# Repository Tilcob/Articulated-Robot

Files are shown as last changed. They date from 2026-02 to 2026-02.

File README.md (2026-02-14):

# 3DOF Robotic Arm Controller (Arduino Nano)

## Overview

This project implements a 3DOF robotic arm controller using an Arduino Nano.
The system includes:

* Analytical forward and inverse kinematics
* Potentiometer-based Cartesian target input (X, Y, Z)
* Button-based target commit (short press)
* Long-press trajectory execution (predefined waypoints)
* Smooth joint motion control
* Configurable servo calibration and joint limits

The kinematic model is consistent with the following convention:

```
x =  cos(q1) * (L1 cos(q2) + L2 cos(q2+q3))
y = -sin(q1) * (L1 cos(q2) + L2 cos(q2+q3))
z =  h + L1 sin(q2) + L2 sin(q2+q3)
```

The negative sign in the Y coordinate is fixed and part of the model.

---

## Hardware Requirements

* Arduino Nano (ATmega328)
* 3 RC servos (Base, Shoulder, Elbow)
* Optional gripper servo
* 3 potentiometers (X, Y, Z)
* Optional gripper potentiometer
* 1 momentary push button
* External 5–6V servo power supply (recommended)

---

## Wiring

### Potentiometers

Each potentiometer:

* One side → 5V
* Other side → GND
* Middle pin → Analog input (A0–A3)

### Button

Configured with `INPUT_PULLUP`.

Wiring:

```
Pin 2  ---- Button ---- GND
```

* Not pressed → HIGH
* Pressed → LOW

### Servos

* Signal pins defined in `Config.h`
* Power servos from external supply
* Connect grounds together (Arduino GND ↔ Servo GND)

---

## Project Structure

* `Config.h` — geometry, limits, pins, calibration
* `Types.h` — basic data structures
* `Kinematics.*` — forward and inverse kinematics
* `Input.*` — potentiometer + button handling
* `Mapping.*` — joint angles → servo degrees
* `Motion.*` — smooth motion controller
* `Trajectory.*` — waypoint-based path execution
* `main.cpp` — system integration

---

## Operation Modes

### 1. Manual Target Mode (Short Button Press)

1. Adjust X, Y, Z using potentiometers.
2. Press the button briefly.
3. The target is latched and the arm moves to that position.

### 2. Trajectory Mode (Long Press > 700 ms)

1. Hold the button.
2. After release, trajectory execution begins.
3. The arm moves through predefined waypoints in `Trajectory.cpp`.

---

## Defining Custom Trajectories

Edit `Trajectory.cpp`:

```cpp
const Waypoint TRAJ_POINTS[] = {
    { {0.11f,  0.00f, 0.09f}, 0.5f },
    { {0.10f,  0.03f, 0.11f}, 0.5f },
    { {0.08f, -0.03f, 0.06f}, 0.2f }
};
```

Each waypoint contains:

* Cartesian position (meters)
* Gripper value (0.0–1.0)

---

## Motion Control

The motion controller:

* Limits joint speed (`MAX_SPEED_DEG_PER_S`)
* Moves joints smoothly toward targets
* Detects arrival within tolerance
* Advances trajectory automatically

---

## Calibration

Adjust in `Config.h`:

* `BASE_ZERO_DEG`
* `SHOULDER_ZERO_DEG`
* `ELBOW_ZERO_DEG`
* `*_SIGN`

Procedure:

1. Move arm mechanically to mathematical zero pose.
2. Set servo zero angles accordingly.
3. Adjust sign if joint moves in wrong direction.

---

## Inverse Kinematics

The IK uses a stable atan2-based solution:

```
q1 = atan2(-y, x)
q3 = atan2(±sqrt(1 - c3²), c3)
q2 = alpha - beta
```

Advantages:

* Stable near singularities
* Supports elbow-up and elbow-down configurations
* No acos flipping issues

---

## Safety Notes

* Always power servos from external supply.
* Avoid commanding unreachable targets.
* Ensure mechanical limits match software limits.

---

Serial Monitor: Permitted coordinates (depending on `h`, `L1`, `L2`)

Entries in the Serial Monitor are **absolute target points in the base coordinate system** in **metres**:

```
x y z [g]
```

* `x, y, z` in metres
* optional `g` as gripper value from `0.0 .. 1.0`

Relative TCP commands are also possible:

```
t dx dy dz [g]
```

Here, `(dx,dy,dz)` is specified in the current TCP coordinate system and is converted internally to the base system.

### Geometric conditions for valid targets

With

* `r = sqrt(x² + y²)`
* `d = sqrt(r² + (z - h)²)`

the following must apply:

* `R_MIN <= r <= R_MAX`
* `Z_MIN <= z <= Z_MAX`
* `|L1 - L2| <= d <= (L1 + L2)`

This is the combination of the configured cylindrical boundaries and the actual 2-link reachability.

### Current figures from `Config.h`

* `L1 = 0.080 m`
* `L2 = 0.068 m`
* `h  = 0.027 m`
* `R_MIN = 0.050 m`
* `R_MAX = L1 + L2 = 0.148 m`
* `Z_MIN = h - 0.02 = 0.007 m`
* `Z_MAX = h + 0.80*(L1+L2) = 0.1454 m`
* Additional IK ring: `0.012 m <= d <= 0.148 m`

### Examples of permitted entries

* `0.10 0.00 0.08`
* `0.09 0.03 0.11 0.6`
* `t 0.01 0.00 -0.01`

If a target is outside the workspace, the firmware reports `WS ERR` or `IK ERR`.

---

## Future Improvements

Possible extensions:

* Cartesian linear interpolation between waypoints
* Trapezoidal acceleration profiles
* Closed-loop control with encoders
* Serial command interface (G-code style)

---

## License

Personal educational project.

---

Developed for Arduino Nano 3DOF robotic arm experimentation.

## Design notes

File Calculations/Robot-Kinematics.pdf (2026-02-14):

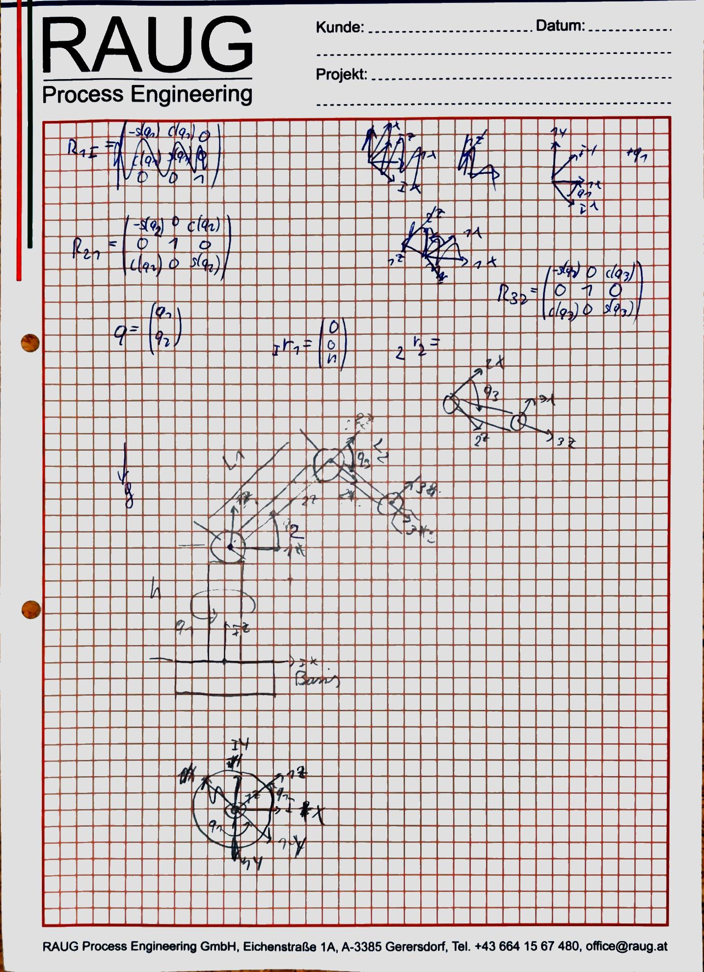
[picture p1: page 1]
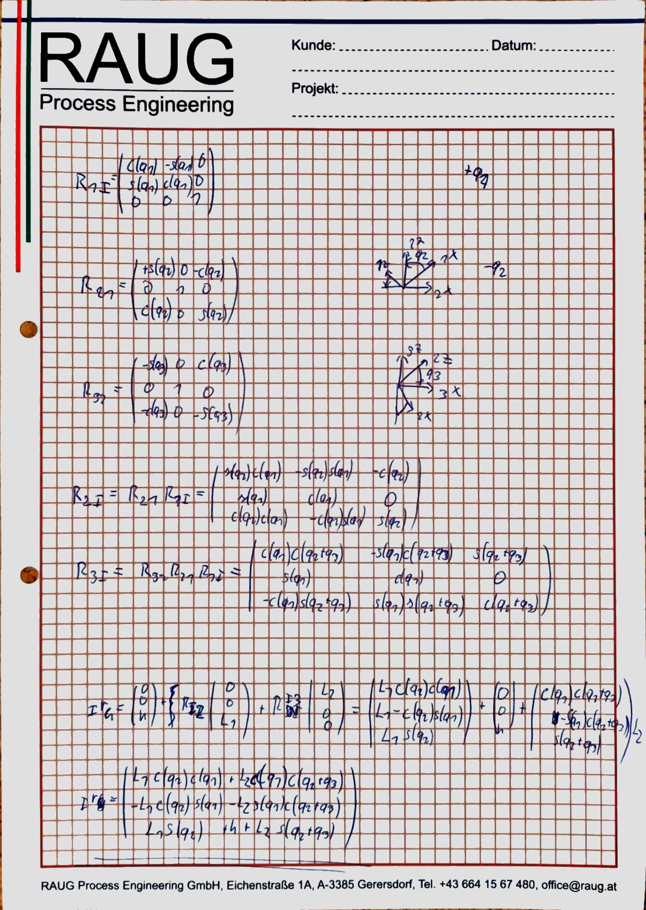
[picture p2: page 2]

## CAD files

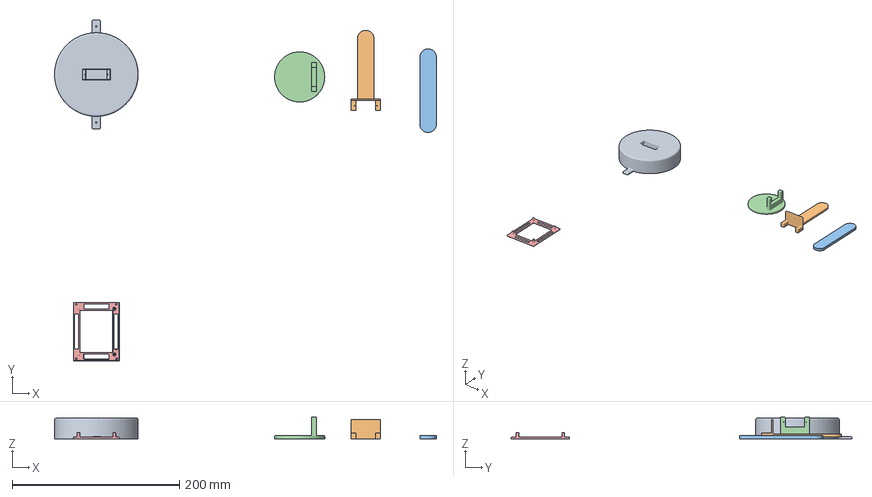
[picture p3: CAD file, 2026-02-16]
CAD/Articulated-Robot.3mf
456.5 x 407.2 x 26.0 mm
Base.stl
L1.stl
L2.stl
Shoulder.stl
PCB-Base.stl

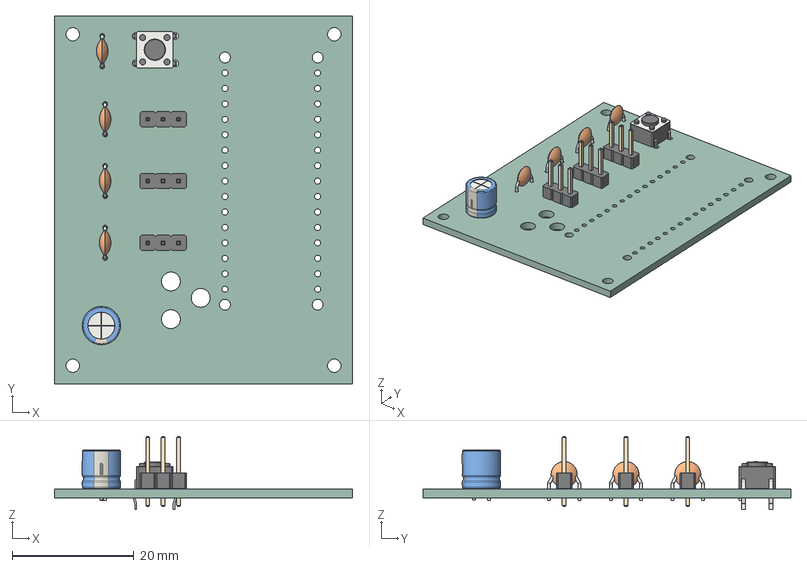
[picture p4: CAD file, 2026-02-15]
Circuit-Diagram/Articulated-Robot/Articulated-Robot.step
49.0 x 60.5 x 12.0 mm
PinHeader_1x03_P2.54mm_Vertical x 3
C_Disc_D4.3mm_W1.9mm_P5.00mm x 4
CP_Radial_D6.3mm_P2.50mm
SW_PUSH_6mm_H4.3mm
Articulated-Robot_PCB

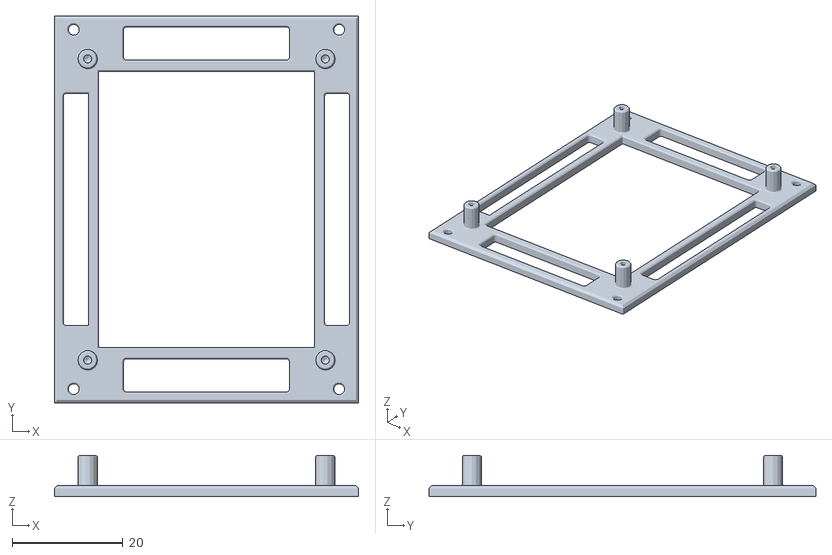
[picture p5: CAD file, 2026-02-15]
CAD/PCB-Base.stl
55.0 x 70.0 x 7.50

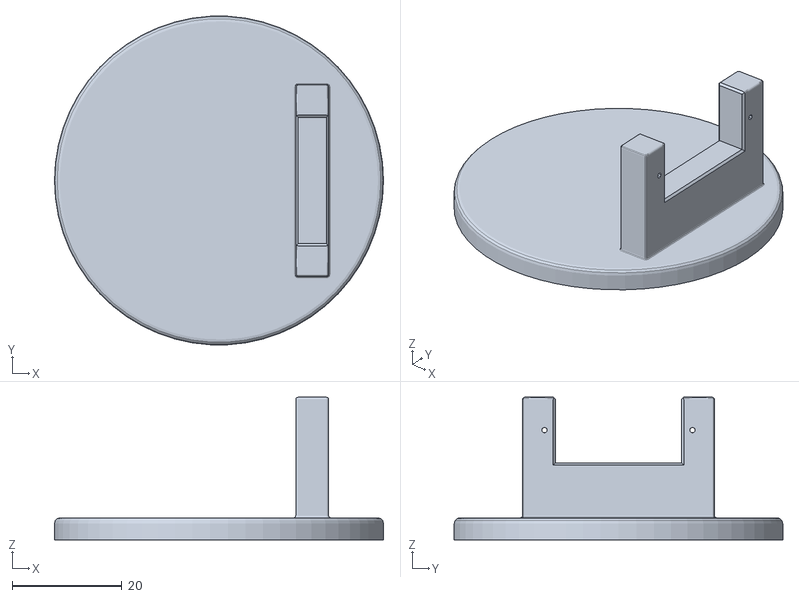
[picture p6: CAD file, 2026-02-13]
CAD/Shoulder.stl
60.0 x 59.9 x 26.0

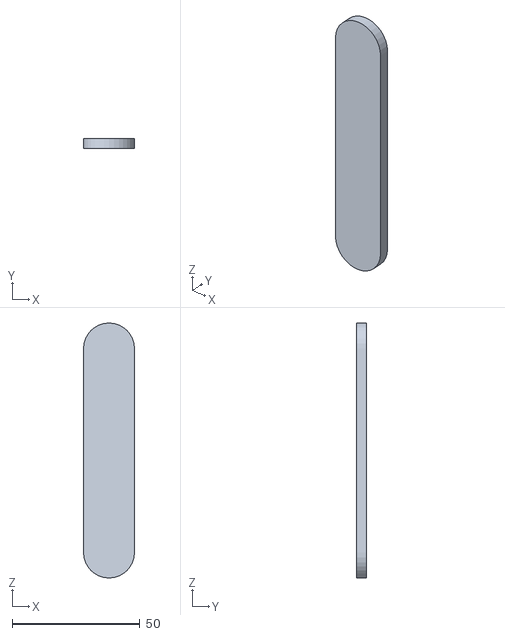
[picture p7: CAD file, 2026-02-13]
CAD/L2.stl
20.0 x 4.00 x 100.0

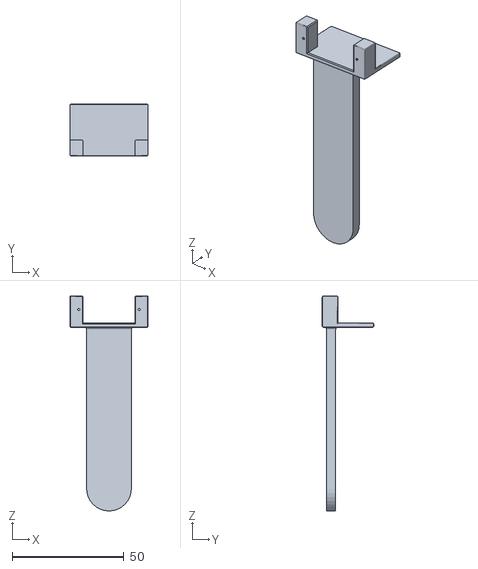
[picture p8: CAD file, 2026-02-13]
CAD/L1.stl
35.0 x 23.0 x 96.0

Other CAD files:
CAD/Articuled-Robot.iam
CAD/Base.iam
CAD/Base.ipt
CAD/L1.ipt
CAD/L2.ipt
CAD/Motor.ipt
CAD/OldVersions/Articuled-Robot.0015.iam
CAD/OldVersions/Base.0003.ipt
CAD/OldVersions/Base.0005.iam
CAD/OldVersions/Base.0012.ipt
CAD/OldVersions/L1.0004.ipt
CAD/OldVersions/L2.0003.ipt
CAD/OldVersions/Motor.0005.ipt
CAD/OldVersions/PCB-Base.0009.ipt
CAD/OldVersions/Shoulder.0004.ipt
CAD/PCB-Base.ipt
CAD/PCB.ipt
CAD/Shoulder.ipt

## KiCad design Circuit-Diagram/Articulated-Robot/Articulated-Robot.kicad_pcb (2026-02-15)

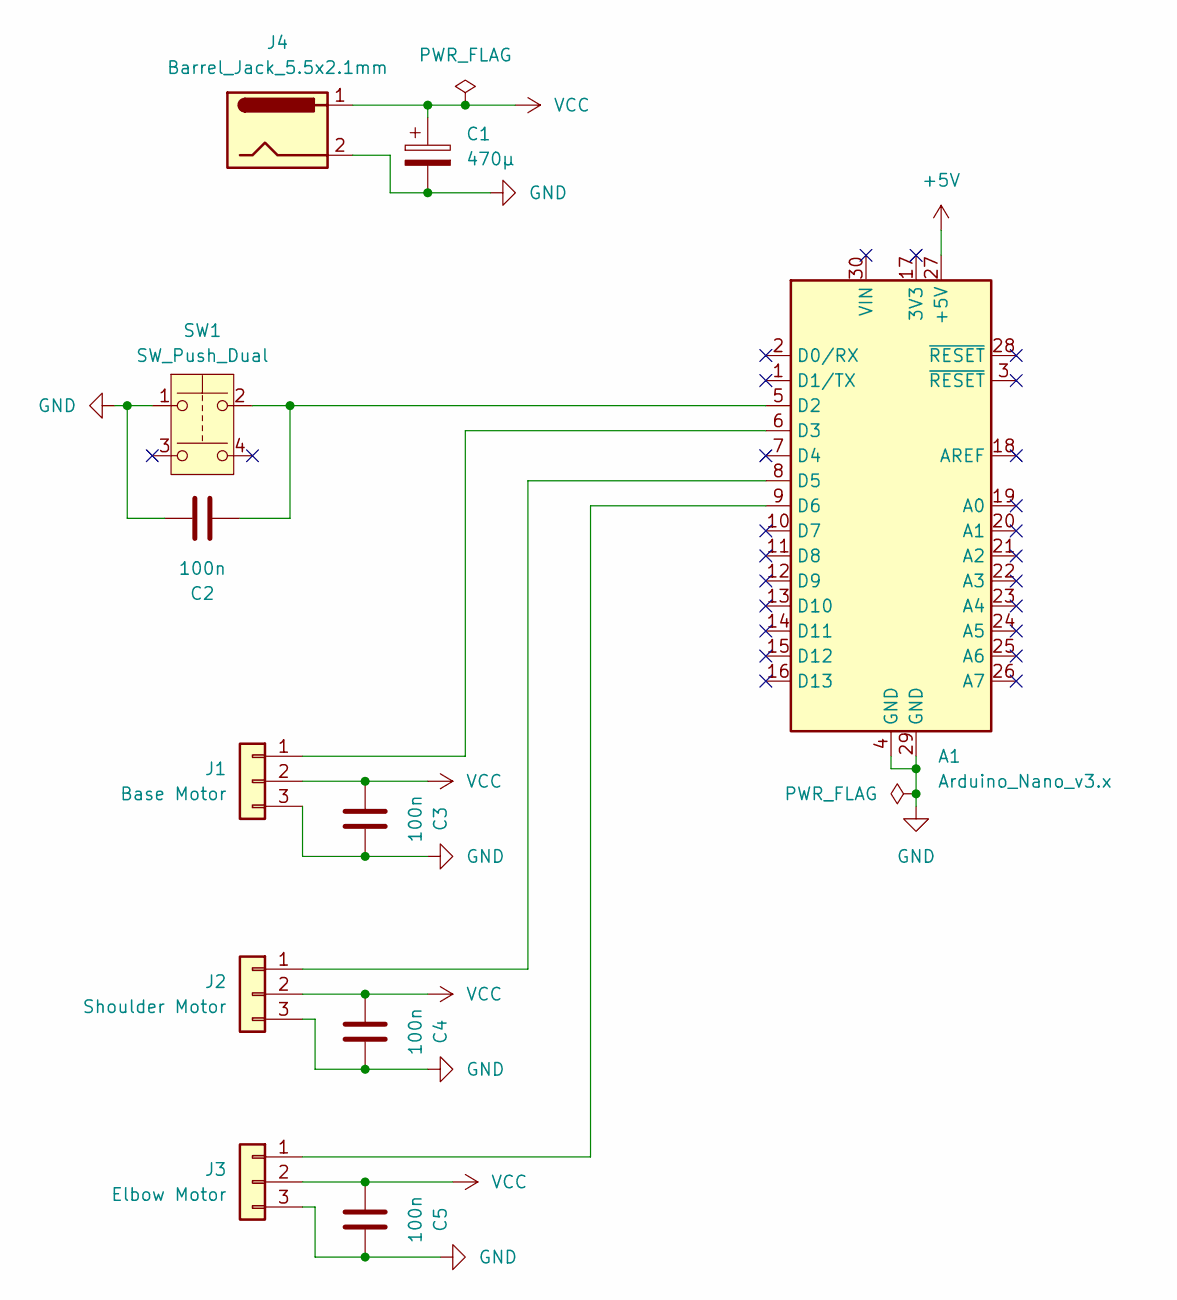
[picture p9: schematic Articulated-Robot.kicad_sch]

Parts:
A1: Arduino_Nano_v3.x; Arduino_Nano_WithMountingHoles
C1: 470µ; CP_Radial_D6.3mm_P2.50mm
C2, C3, C4, C5: 100n; C_Disc_D4.3mm_W1.9mm_P5.00mm
J1: Base Motor; PinHeader_1x03_P2.54mm_Vertical
J2: Shoulder Motor; PinHeader_1x03_P2.54mm_Vertical
J3: Elbow Motor; PinHeader_1x03_P2.54mm_Vertical
J4: Barrel_Jack_5.5x2.1mm
SW1: SW_Push_Dual; SW_PUSH_6mm_H4.3mm

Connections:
+5V: A1.27 (+5V)
GND: A1.4 (GND), A1.29 (GND), C1.2, C2.1, C3.1, C4.1, C5.1, J1.3, J2.3, J3.3, J4.2, SW1.1
unnamed: A1.5 (D2), C2.2, SW1.2
unnamed: A1.6 (D3), J1.1
unnamed: A1.8 (D5), J2.1
unnamed: A1.9 (D6), J3.1
VCC: C1.1, C3.2, C4.2, C5.2, J1.2, J2.2, J3.2, J4.1

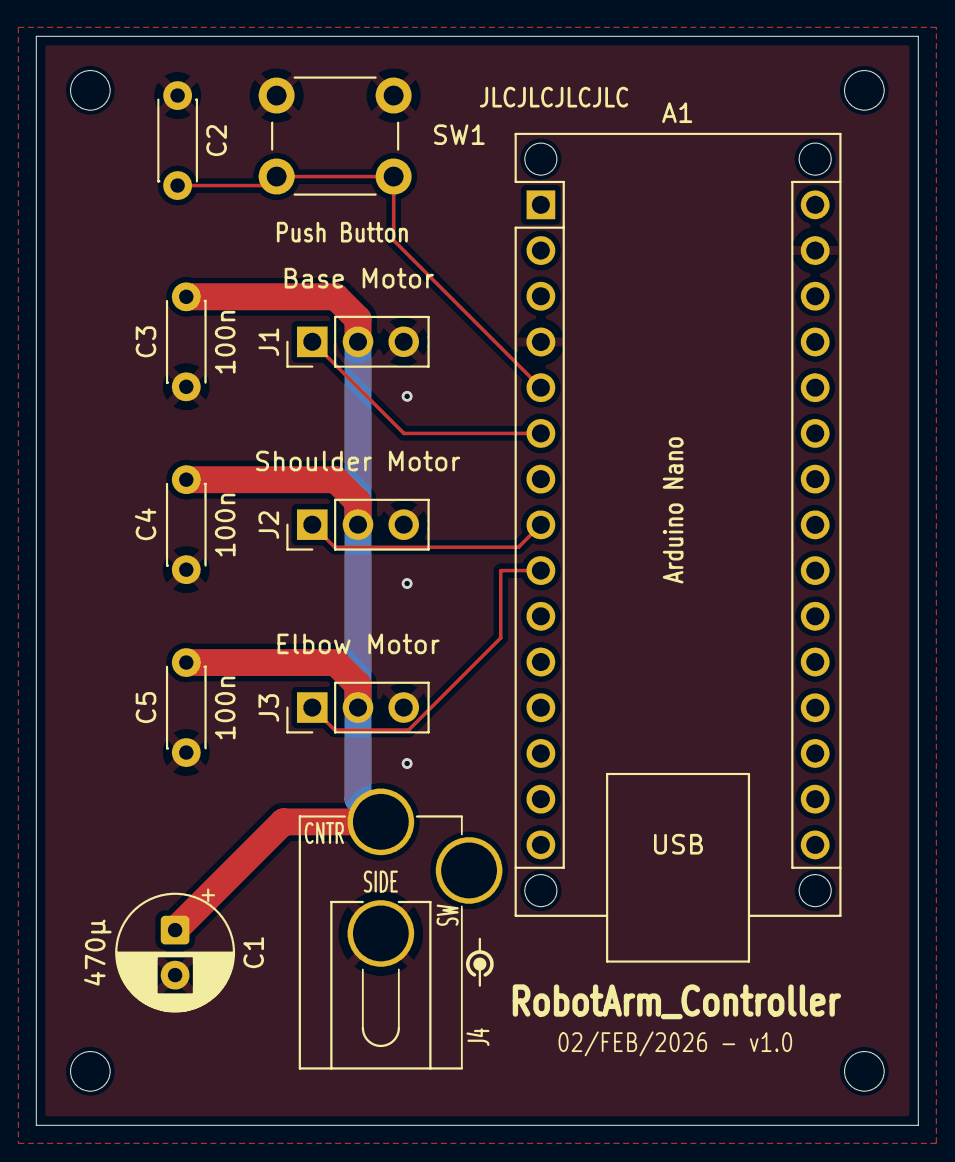
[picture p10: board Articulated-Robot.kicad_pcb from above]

Board: 2 copper layers, 49.0 x 60.5 mm, 11 parts (0 on the bottom side), 6 nets.

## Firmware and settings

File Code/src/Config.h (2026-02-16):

#pragma once
#include <Arduino.h>

// Central configuration for geometry, IO pins, joint/servo conventions and limits.
// Keep this header lightweight and purely constexpr.
namespace cfg {

static constexpr float DEG2RAD = PI / 180.0f;
static constexpr float RAD2DEG = 180.0f / PI;

// --- Geometry ----------------------------------------------------------
static constexpr float L1 = 0.080f;  // [m]
static constexpr float L2 = 0.068f;  // [m]
static constexpr float h  = 0.027f;  // [m]

// Workspace limits
static constexpr float R_MIN = 0.0f;
static constexpr float R_MAX = L1 + L2;
static constexpr float Z_MIN = h - 0.02f;
static constexpr float Z_MAX = h + L1 + L2;

static constexpr bool ELBOW_UP = false;

// --- IO pins -----------------------------------------------------------
// Momentary button (Taster). Wiring: pin -> button -> GND (uses INPUT_PULLUP).
static constexpr uint8_t PIN_BTN_COMMIT = 2;

static constexpr uint8_t PIN_POT_X = A0;
static constexpr uint8_t PIN_POT_Y = A1;
static constexpr uint8_t PIN_POT_Z = A2;
static constexpr uint8_t PIN_POT_G = A3;

static constexpr uint8_t PIN_SERVO_BASE     = 3;
static constexpr uint8_t PIN_SERVO_SHOULDER = 5;
static constexpr uint8_t PIN_SERVO_ELBOW    = 6;
static constexpr uint8_t PIN_SERVO_GRIPPER  = 9;

// ADC
static constexpr int ADC_MIN = 0;
static constexpr int ADC_MAX = 1023;

// --- Servo range -------------------------------------------------------
static constexpr float SERVO_MIN_DEG = 0.0f;
static constexpr float SERVO_MAX_DEG = 180.0f;

// --- Joint<->Servo mapping --------------------------------------------
// Convention:
//   servoDeg = zeroDeg + sign * jointDeg
// where jointDeg is q in degrees.
static constexpr float BASE_ZERO_DEG     = 0.0f;
static constexpr float SHOULDER_ZERO_DEG = 0.0f;
static constexpr float ELBOW_ZERO_DEG    = 0.0f;

static constexpr int BASE_SIGN     = +1;
static constexpr int SHOULDER_SIGN = +1;
static constexpr int ELBOW_SIGN    = +1;

static constexpr float jointRadFromServoDeg(const float servoDeg, const float zeroDeg, int sign) {
  // jointDeg = (servoDeg - zeroDeg)/sign
  return ((servoDeg - zeroDeg) / static_cast<float>(sign)) * DEG2RAD;
}

static constexpr float Q1_A = jointRadFromServoDeg(SERVO_MIN_DEG, BASE_ZERO_DEG, BASE_SIGN);
static constexpr float Q1_B = jointRadFromServoDeg(SERVO_MAX_DEG, BASE_ZERO_DEG, BASE_SIGN);
static constexpr float Q1_MIN = (Q1_A < Q1_B) ? Q1_A : Q1_B;
static constexpr float Q1_MAX = (Q1_A < Q1_B) ? Q1_B : Q1_A;

static constexpr float Q2_A = jointRadFromServoDeg(SERVO_MIN_DEG, SHOULDER_ZERO_DEG, SHOULDER_SIGN);
static constexpr float Q2_B = jointRadFromServoDeg(SERVO_MAX_DEG, SHOULDER_ZERO_DEG, SHOULDER_SIGN);
static constexpr float Q2_MIN = (Q2_A < Q2_B) ? Q2_A : Q2_B;
static constexpr float Q2_MAX = (Q2_A < Q2_B) ? Q2_B : Q2_A;

static constexpr float Q3_A = jointRadFromServoDeg(SERVO_MIN_DEG, ELBOW_ZERO_DEG, ELBOW_SIGN);
static constexpr float Q3_B = jointRadFromServoDeg(SERVO_MAX_DEG, ELBOW_ZERO_DEG, ELBOW_SIGN);
static constexpr float Q3_MIN = (Q3_A < Q3_B) ? Q3_A : Q3_B;
static constexpr float Q3_MAX = (Q3_A < Q3_B) ? Q3_B : Q3_A;

// --- Motion limits -----------------------------------------------------
static constexpr float MAX_SPEED_DEG_PER_S = 60.0f;
static constexpr float MAX_ACC_DEG_PER_S2  = 120.0f;
static constexpr float LOOP_DT_S           = 0.02f;  // nominal loop time

// Debug: print a warning (rate-limited) if any servo command saturates at 0..180.
static constexpr bool ENABLE_SERVO_SAT_WARN = true;
static constexpr unsigned long SERVO_SAT_WARN_PERIOD_MS = 1000;

// Trajectory timing (time per segment between two waypoints)
static constexpr float TRAJ_SEG_TIME_S = 0.5f;

// Optional startup calibration loop.
static constexpr bool ENABLE_CALIBRATION_MODE = false;

}

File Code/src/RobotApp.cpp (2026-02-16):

#include "RobotApp.h"
#include <Servo.h>

#include "Config.h"
#include "Types.h"
#include "Input.h"
#include "Kinematics.h"
#include "Mapping.h"
#include "Motion.h"
#include "Trajectory.h"

#include "ServoIO.h"
#include "SerialControl.h"

static Servo servoBase, servoShoulder, servoElbow, servoGripper;
static MotionController motion;

static unsigned long lastMs = 0;

static Vec3 committedTargetPosition{};
static float committedGripper = 0.0f;
static bool hasCommitted = false;

static Trajectory traj;
static bool trajMode = false;

static bool btnWasDown = false;
static unsigned long pressStartMs = 0;
static constexpr unsigned long LONG_PRESS_MS = 700;

static Angles lastCommandQ{};
static Vec3   lastTcpPosBase{};
static Mat3   lastRBaseTcp{};
static bool   havePose = false;

// Homing
static bool homingFlag = true;
static ServoAngles homeServo{};

// Debug
static bool debugPrint = false;
static unsigned long lastDbgMs = 0;
static constexpr unsigned long DBG_PERIOD_MS = 200;

static float calDeltaTime() {
  const unsigned long now = millis();
  const float dt = (now - lastMs)/1000.0f;
  lastMs = now;
  return constrain(dt, cfg::LOOP_DT_S, 0.05f);
}

static void homing(const float dt) {
  const ServoAngles cur = motion.stepToward(homeServo, dt, cfg::MAX_SPEED_DEG_PER_S, cfg::MAX_ACC_DEG_PER_S2);
  writeServos(servoBase, servoShoulder, servoElbow, servoGripper, cur);

  if (arrived(cur, homeServo)) {
    homingFlag = false;

    lastCommandQ = Angles{0,0,0};
    lastTcpPosBase = forwardKinematics(lastCommandQ, cfg::L1, cfg::L2, cfg::h);
    lastRBaseTcp = tcpRotationBase(lastCommandQ);
    havePose = true;

    Serial.println("HOMING done.");
  }
}

static void handleButtonPress(const InputState &inputState, const unsigned long now) {
  if (inputState.commitPressed) {
    btnWasDown = true;
    pressStartMs = now;
  }
  if (btnWasDown && !inputState.commitDown) {
    const unsigned long pressMs = now - pressStartMs;
    btnWasDown = false;

    if (pressMs >= LONG_PRESS_MS) {
      traj.reset();
      trajMode = true;
      hasCommitted = true;
      Serial.println("TRAJ start");
    } else {
      trajMode = false;
      committedTargetPosition = inputState.target;
      committedGripper = inputState.gripper01;
      hasCommitted = true;
      Serial.println("COMMIT manual target");
    }
  }
}

void robotSetup() {
  Serial.begin(115200);

  attachServos(servoBase, servoShoulder, servoElbow, servoGripper);

  Serial.println("CALIB MODE: type: b <deg>, s <deg>, e <deg>, p=print, x=exit");
  ServoAngles cal{};
  cal.baseDeg = 90; cal.shoulderDeg = 90; cal.elbowDeg = 90; cal.gripperDeg = 60;
  writeServos(servoBase, servoShoulder, servoElbow, servoGripper, cal);

  while (cfg::ENABLE_CALIBRATION_MODE) {
    if (!Serial.available()) continue;
    const char cmd = Serial.read();
    if (cmd == '\n' || cmd == '\r' || cmd == ' ') continue;

    if (cmd == 'x') break;
    if (cmd == 'p') {
      Serial.print("B="); Serial.print(cal.baseDeg);
      Serial.print(" S="); Serial.print(cal.shoulderDeg);
      Serial.print(" E="); Serial.println(cal.elbowDeg);
      continue;
    }

    float v = Serial.parseFloat();
    v = constrain(v, cfg::SERVO_MIN_DEG, cfg::SERVO_MAX_DEG);

    if (cmd == 'b') cal.baseDeg = v;
    if (cmd == 's') cal.shoulderDeg = v;
    if (cmd == 'e') cal.elbowDeg = v;

    writeServos(servoBase, servoShoulder, servoElbow, servoGripper, cal);
  }


  ServoAngles start{};
  start.baseDeg = cfg::BASE_ZERO_DEG;
  start.shoulderDeg = cfg::SHOULDER_ZERO_DEG;
  start.elbowDeg = cfg::ELBOW_ZERO_DEG;
  start.gripperDeg = 60;

  motion.setCurrent(start);
  writeServos(servoBase, servoShoulder, servoElbow, servoGripper, start);

  constexpr Angles homeQ{0,0,0};
  homeServo = mapToServos(homeQ, 0.5f);
  homingFlag = true;
  Serial.println("HOMING: moving to q=(0,0,0)");

  lastMs = millis();
  initInputs();

  committedTargetPosition = Vec3{(cfg::L1 + cfg::L2) * 0.8f, 0, cfg::h};
  committedGripper = 0.5f;
  hasCommitted = false;
}

void log_debug_information(const Vec3 &target, const IKResult &result) {
  const unsigned long nowMs = millis();
  if (nowMs - lastDbgMs >= DBG_PERIOD_MS) {
    lastDbgMs = nowMs;
    const Vec3 fk = lastTcpPosBase;
    Serial.print("DBG err: ");
    Serial.print(target.x - fk.x,4); Serial.print(" ");
    Serial.print(target.y - fk.y,4); Serial.print(" ");
    Serial.print(target.z - fk.z,4);
    Serial.print(" | q: ");
    Serial.print(result.q.q1*180/PI,1); Serial.print(" ");
    Serial.print(result.q.q2*180/PI,1); Serial.print(" ");
    Serial.print(result.q.q3*180/PI,1);
    Serial.println();
  }
}

static Vec3 clampToReachable(Vec3 t) {
  const float r = sqrtf(t.x*t.x + t.y*t.y);
  const float z = t.z - cfg::h;
  const float d = sqrtf(r*r + z*z);

  const float dMin = fabsf(cfg::L1 - cfg::L2);
  constexpr float dMax = cfg::L1 + cfg::L2;
  constexpr float EPS = 1e-4f;

  if (d < EPS) return t;

  if (d > dMax) {
    const float s = dMax / d;
    t.x *= s; t.y *= s;
    t.z = cfg::h + z * s;
  } else if (d < dMin) {
    const float s = dMin / d;
    t.x *= s; t.y *= s;
    t.z = cfg::h + z * s;
  }
  return t;
}
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

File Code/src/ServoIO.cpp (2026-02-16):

#include "ServoIO.h"
#include "Config.h"
#include "Util.h"
#include <math.h>

bool arrived(const ServoAngles& cur, const ServoAngles& tgt) {
	constexpr float tol = 1.0f;
	return util::nearf(cur.baseDeg,     tgt.baseDeg,     tol) &&
		   util::nearf(cur.shoulderDeg, tgt.shoulderDeg, tol) &&
		   util::nearf(cur.elbowDeg,    tgt.elbowDeg,    tol) &&
		   util::nearf(cur.gripperDeg,  tgt.gripperDeg,  tol);
}

void attachServos(Servo& base, Servo& shoulder, Servo& elbow, Servo& gripper) {
	base.attach(cfg::PIN_SERVO_BASE);
	shoulder.attach(cfg::PIN_SERVO_SHOULDER);
	elbow.attach(cfg::PIN_SERVO_ELBOW);
	gripper.attach(cfg::PIN_SERVO_GRIPPER);
}

void writeServos(Servo& base, Servo& shoulder, Servo& elbow, Servo& gripper, const ServoAngles& a) {
	base.write(static_cast<int>(lroundf(a.baseDeg)));
	shoulder.write(static_cast<int>(lroundf(a.shoulderDeg)));
	elbow.write(static_cast<int>(lroundf(a.elbowDeg)));
	gripper.write(static_cast<int>(lroundf(a.gripperDeg)));
}

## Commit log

2026-02-13 Updated the kinematics to the calculated angles and positions.
2026-02-13 Add README for 3DOF Robotic Arm Controller
    Added comprehensive documentation for the 3DOF robotic arm controller project, including hardware requirements, wiring instructions, project structure, operation modes, and safety notes.
2026-02-13 Made the cad for the robot
    [Articulated-Robot.3mf, Articuled-Robot.0012.iam, Articuled-Robot.iam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]
2026-02-14 Added KiCad and fixed the q3 bug.
    [Articulated-Robot.kicad_pcb, Articulated-Robot.kicad_sch]
2026-02-14 Fixed the mapping bug.
    [Config.h]
2026-02-15 Made and ordered a pcb for the circuit.
    [Articulated-Robot-B_Mask.gbs, Articulated-Robot-B_Paste.gbp, Articulated-Robot-B_SilkS.gbo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]
2026-02-16 Made some minor adjustments to the motion controller and added a new function to clamp floats.
2026-02-16 Made the trajectory class more efficient and added a new function to clamp floats.
2026-02-16 Optimized trajectory points, added calibration mode, and improved servo saturation handling.
